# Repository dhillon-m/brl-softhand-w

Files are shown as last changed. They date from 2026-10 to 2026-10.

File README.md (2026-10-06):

# SoftHand Model-W

**A 3D-printed, anthropomorphic, underactuated robot hand with an integrated wrist and carpal tunnel**






Dhillon B. Merritt, Christopher J. Ford, Haoran Li, Malia Smith, Zhixing Chen, Efi Psomopoulou\*, Nathan F. Lepora\*  
*Bristol Robotics Laboratory, University of Bristol* · \*Equal contribution

This repository contains the CAD (STEP) and Python control code for the **SoftHand Model-W (SoftHand-W)**. The SoftHand-W is a 3D-printed hand based on the Pisa/IIT SoftHand. It adds an antagonistic tendon mechanism and a **2-DoF tendon-driven wrist**. Four servos drive it:

- **Fingers:** active flexion and extension of all five fingers.
- **Wrist:** active flexion/extension and radial/ulnar deviation of the palm.

The hand keeps the synergistic, self-adaptive grasping of the SoftHand family.

📄 **Paper:** [arXiv:2604.00738](https://arxiv.org/abs/2604.00738)

---

## Contents

- [Highlights](#highlights)
- [Hardware](#hardware)
- [CAD](#cad)
- [Software](#software)
- [Getting started](#getting-started)
- [Library reference](#library-reference)
- [Experiments](#experiments)
- [Citation](#citation)
- [Acknowledgements](#acknowledgements)
- [License](#license)

## Highlights

- **Underactuated and anthropomorphic.** Five fingers move together through adaptive synergies, driven by antagonistic flexor and extensor tendons.
- **2-DoF wrist** in a serial rotational-rotational layout:
  - **±90°** flexion/extension
  - **±30°** radial/ulnar deviation
- **Carpal-tunnel tendon routing.** The finger tendons pass through the wrist inside PTFE sheaths that work like Bowden cables. This means:
  - Moving the wrist doesn't make the fingers flex.
  - The motors can sit in the forearm, which keeps weight away from the hand.
- **Human-scale.** The hand is 164.6 mm from the base of the palm to the middle fingertip, which is within the 5th–95th percentile of adult hands.
- **Low-cost and easy to build.** It uses printed PLA, off-the-shelf servos and common hardware.

## Hardware

| Component | Details |
| --- | --- |
| Actuators | 4 × Feetech STS3215 serial bus servos (19.5 kg·cm at 7.4 V) |
| Servo interface | Feetech URT-1 controller, USB to PC |
| Structure | PLA (FDM); small precision parts in resin (SLA); CNC-milled aluminium parts |
| Tendons | Nylon thread, routed through PTFE tubing (carpal tunnel) |
| Fasteners | M2 screws and bearings. Tendons are anchored with an M2 bolt and washers, not knots. |
| Hand size | 164.6 mm tall; each finger 81.6 mm long |
| Wrist size | 54.5 mm (H) × 69.3 mm (W) × 41 mm (D) |
| Robot arm | Tested on a Universal Robots UR5 |

### Servo IDs

The code assumes the following servo IDs:

| ID | Function |
| -- | --- |
| 1  | Wrist flexion / extension |
| 2  | Finger extensor |
| 3  | Finger flexor |
| 4  | Wrist radial / ulnar deviation |

### Wrist kinematics

Distal Denavit–Hartenberg parameters of the wrist:

| Joint | Motion | a (mm) | α | d | θ  |
| ----- | --- | --- | --- | - | -- |
| 1 | Ulnar / radial deviation | 34 | π/2 | 0 | θ₁ |
| 2 | Flexion / extension | 48 | 0 | 0 | θ₂ |

## CAD

All parts are STEP files in [`cad/`](cad), grouped the same way as the original design. [`Assembly - Final.step`](cad) is the complete hand and wrist.

| Folder | Contents |
| --- | --- |
| [`cad/Fingers/`](cad/Fingers) | Proximal, intermediate and distal phalanges, the middle gear, phalange connectors, and a full finger assembly (plus an exploded view) |
| [`cad/Palm/`](cad/Palm) | Palm, palm covers, and the finger and palm layout |
| [`cad/Wrist/`](cad/Wrist) | The 2-DoF wrist (assembled and exploded) and the 16 mm bearing |
| [`cad/Actuation/`](cad/Actuation) | Tendon spools (finger, flexion, deviation), servo adapter, Bowden guides, and reference models of the STS3215 servo and 7 mm bearing |
| [`cad/Testing/`](cad/Testing) | Experiment parts: a UR5 tool flange adapter, a retaining bracket, the test cube and reorientation die, and a screw test piece |

The servo and bearing models are there for fitting checks only. Those parts are bought, not printed.

## Software

| File | Purpose |
| --- | --- |
| [`softhand_w_lib.py`](softhand_w_lib.py) | Servo control library: raw Feetech packet commands, hand open/close, wrist angle control and tool centre point (TCP) calculation |
| [`test_script.py`](test_script.py) | Cube-stacking experiment on a UR5. It logs joint angles and pose to CSV and plots the results. |

Wrist control is **open loop and proportional**. A requested angle is turned into a servo position by multiplying it by a constant gain and offsetting it from a calibrated centre value. Because the wrist moves the hand, the tool centre point also moves. `test_script.py` can run a background thread that recomputes the robot's TCP from the current wrist angles.

## Getting started

### Requirements

- Python 3.10+
- [`pyserial`](https://pypi.org/project/pyserial/), `numpy`, `matplotlib`
- For the UR5 experiments only: the Common Robot Interface (`cri`) package, which provides `SyncRobot`, `AsyncRobot` and `RTDEController`.

```sh
pip install pyserial numpy matplotlib
```

### Calibrate your hand

> ⚠️ **The servo positions in `softhand_w_lib.py` belong to one particular build.** Tendon length and how the horns are mounted differ between builds. Using these positions without checking them can over-tension the tendons.

1. Use the Feetech debugging software to find the open and closed positions of the flexor servo (ID 3) and the extensor servo (ID 2).
2. Update the values in `open_hand()` and `close_hand()`.
3. Check the wrist centre values in `move_wrist()` and `get_wrist_angles()`: `2048` for flexion and `2150` for deviation. Also check the travel limits.

### Minimal example

```python
import serial
import softhand_w_lib as swl

ser = serial.Serial("COM5", baudrate=1_000_000, timeout=0.1)  # change to your port

swl.home_hand(ser)                                   # open hand, centre wrist
swl.close_hand(ser)
swl.wait_for_servo(ser, servo_ids=[2, 3])

swl.move_wrist(ser, flexion_angle=45, ulnar_angle=0) # degrees
swl.wait_for_servo(ser, servo_ids=[1, 4])
print(swl.get_wrist_angles(ser))                     # (flexion°, ulnar°)

swl.open_hand(ser)
ser.close()
```

## Library reference

| Function | Description |
| --- | --- |
| `move_servo(ser, servo_id, position)` | Sends a raw position command (0–4095). |
| `read_servo_position(ser, servo_id)` | Reads the servo's current position, or returns `None` on error. |
| `read_servo_moving(ser, servo_id)` | Returns `True` if the servo is moving. |
| `wait_for_servo(ser, servo_ids, check_interval, timeout)` | Waits until every listed servo has stopped. |
| `open_hand(ser)` / `close_hand(ser)` | Drives the antagonistic flexor/extensor pair, in the right order. |
| `move_wrist(ser, flexion_angle, ulnar_angle)` | Moves the wrist to the given angles in degrees. Positions are clamped to safe limits. |
| `get_wrist_angles(ser)` | Reads the current wrist angles in degrees. |
| `compute_tcp_from_wrist(flexion_angle, ulnar_angle)` | Returns the TCP pose `[x, y, z, ax, ay, az]` for a 285 mm hand offset. |
| `home_hand(ser)` | Opens the hand, centres the wrist and waits for all servos to stop. |

Every serial access goes through one shared re-entrant lock, `swl.serial_lock`, so the library can be called from several threads, for example a logger and a TCP updater. Scripts should use this lock rather than creating their own.

## Experiments

The SoftHand-W was mounted on a UR5 and tested on two reorientation tasks. Each task was run with the wrist actuated and with it held fixed.

| Task | Without wrist | With wrist |
| --- | --- | --- |
| **Disc rotation** (90 mm disc, rotated 90°): time  | 66 s | **47 s** (~29% faster) |
| **Disc rotation**: configuration changes | 2 | **1** |
| **Cube stacking** (six 50 mm cubes): cubes stacked | 5 / 6 | **6 / 6** |
| **Cube stacking**: max travel of UR5 joint 4 | baseline | **~36% less** |

Using the wrist cut down how much the arm had to move to compensate, made the tasks faster, and made some pick-and-place moves possible that couldn't be done otherwise.

To rerun the cube-stacking task:

1. Set the serial port (`COM5`) and the UR5 IP address in `test_script.py`.
2. Check the cube and placement poses for your workspace.
3. Run `python test_script.py`. Logged data goes to `stack_no_wrist.csv`, and plots of joint angles and the end-effector path are shown at the end.

## Citation

If you use this work, please cite:

```bibtex
@article{merritt2026softhandw,
  title   = {SoftHand Model-W: A 3D-Printed, Anthropomorphic, Underactuated Robot Hand with Integrated Wrist and Carpal Tunnel},
  author  = {Merritt, Dhillon B. and Ford, Christopher J. and Li, Haoran and Smith, Malia and Chen, Zhixing and Psomopoulou, Efi and Lepora, Nathan F.},
  journal = {arXiv preprint arXiv:2604.00738},
  year    = {2026}
}
```

## Acknowledgements

This work was supported by the Advanced Research + Invention Agency (ARIA) under the grant *"Democratising Co-Design of Hardware and Control for Robot Dexterity"*.

The design builds on the Pisa/IIT SoftHand and the BRL SoftHand line, including the [MagProprio SoftHand](https://github.com/robotdexterity/MIT-x-BRL-Robot-Hand-with-Proprioception).

## License

Everything in this repository, including the code and the CAD files, is released under the [MIT License](LICENSE).

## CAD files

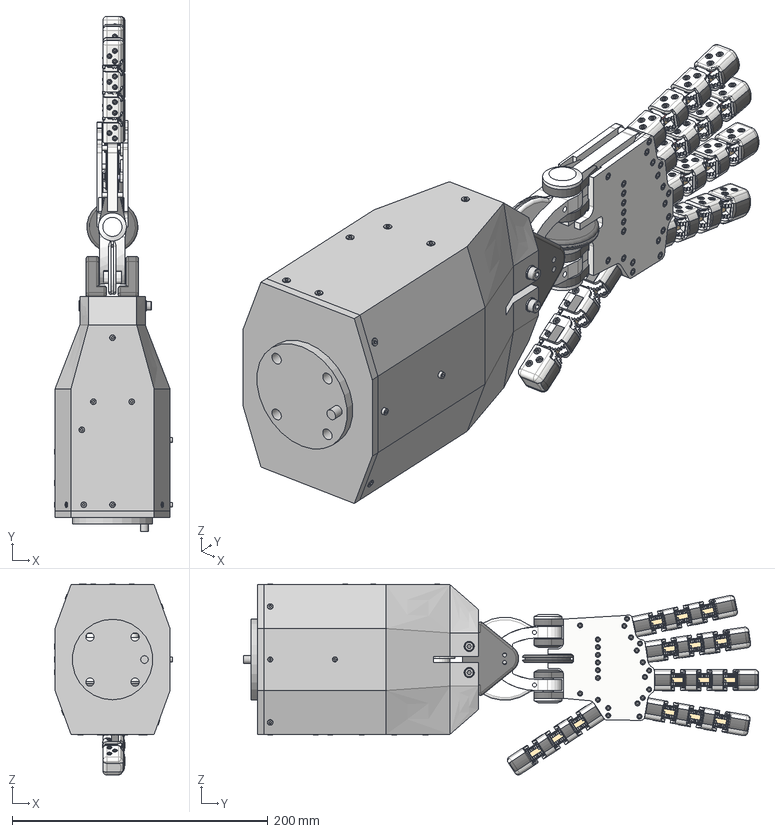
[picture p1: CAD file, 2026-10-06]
cad/Assembly - Final.step
92.5 x 402.9 x 149.4 mm
Servo - Feetech STS3215 x 4
Servo Adapter x 4
Front
Outer Ring x 4
Inner Ring x 4
Base Rear (1)
Base Front (1)
Deviation Axle (1)
Middle Link
Flex/Ext Axle
Flex/Ext Axle (1)
Cap x 2
M2_8mm x 25
phalange connector 11.95 mm x 15
Ring Magnet x 15
small bearing (ID is off) x 144
M2_10mm x 40
M2_5mm x 80
Middle Gear x 10
Pyramid Side Cover x 10
V Side Cover x 10
Cable- Pyr Side x 10
Cable- V Side x 10
3D FPC PLACEHOLDER NO LINK
3D FPC PLACEHOLDER NO LINK_1
middle gear_1 x 5
pyramid side cover_1 x 5
v side cover_1 x 5
CAPC1608X85 x 10
Middle Gear_2 x 5
Pyramid Side Cover_2 x 5
V Side Cover_2 x 5
Cable- Pyr Side_1 x 5
Cable- V Side_1 x 5
3D FPC PLACEHOLDER NO LINK_3
3D FPC PLACEHOLDER NO LINK_4
3D FPC PLACEHOLDER NO LINK_6
3D FPC PLACEHOLDER NO LINK_7
3D FPC PLACEHOLDER NO LINK_9
3D FPC PLACEHOLDER NO LINK_10
3D FPC PLACEHOLDER NO LINK_12
3D FPC PLACEHOLDER NO LINK_13
Flex/Ext Pulley
Palm_1
Back Cover
Inner Palm Cover
OT
IT
IP
OP
UR5 Tool Flange Adapter v2
Back
Bracket
Bracket finger
NF E25-514 - Z2.5 Steel 100 HV Plain x 24
DIN 912 - M2 x 0.4 x 5 Steel 4.6 Plain x 12
7mm OD 2mm ID Bearing x 4
DIN 912 - M2 x 0.4 x 10 Steel 4.6 Plain x 5
DIN 912 - M2.5 x 0.45 x 8 Steel 4.6 Plain x 30
NF E25-514 - Z4 Steel 100 HV Plain x 4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

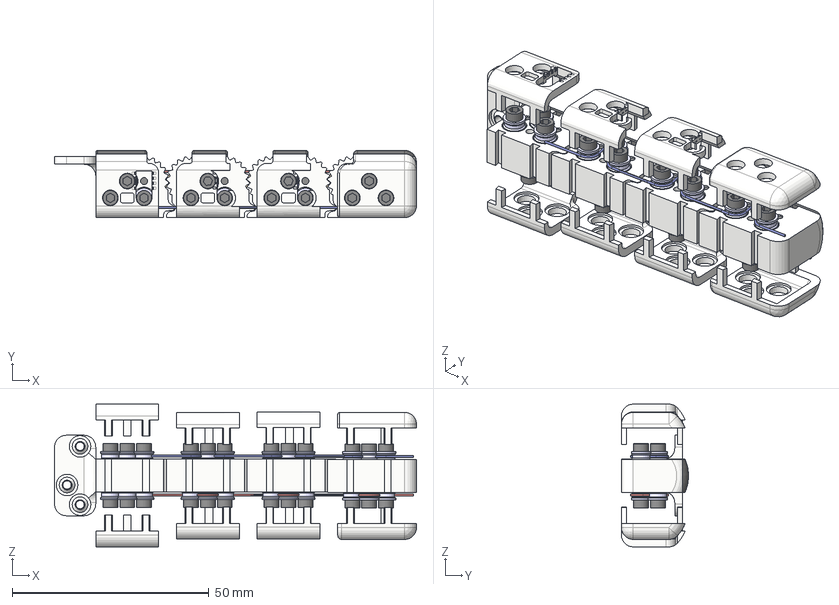
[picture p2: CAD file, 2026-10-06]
cad/Fingers/Assembled Finger - Exploded.step
92.1 x 17.1 x 36.3 mm
small bearing (ID is off) x 18
M2_10mm x 6
M2_5mm x 12
Middle Gear (2)
Pyramid Side Cover (2)
V Side Cover (2)
Cable- Pyr Side (2)
Cable- V Side (2)
Middle Gear (1)
Pyramid Side Cover (1)
V Side Cover (1)
Cable- Pyr Side (1)
Cable- V Side (1)
phalange connector 11.95 mm x 3
Ring Magnet x 3
small bearing (ID is off) v1
small bearing (ID is off) v1 (1)
small bearing (ID is off) v1 (2)
small bearing (ID is off) v1 (3)
small bearing (ID is off) v1 (4)
small bearing (ID is off) v1 (5)
M2_10mm v2
M2_10mm v2 (1)
M2_5mm v2
M2_5mm v2 (1)
M2_5mm v2 (2)
M2_5mm v2 (3)
middle gear
pyramid side cover
v side cover
Middle Gear_1
Pyramid Side Cover_1
V Side Cover_1
Cable- Pyr Side
Cable- V Side

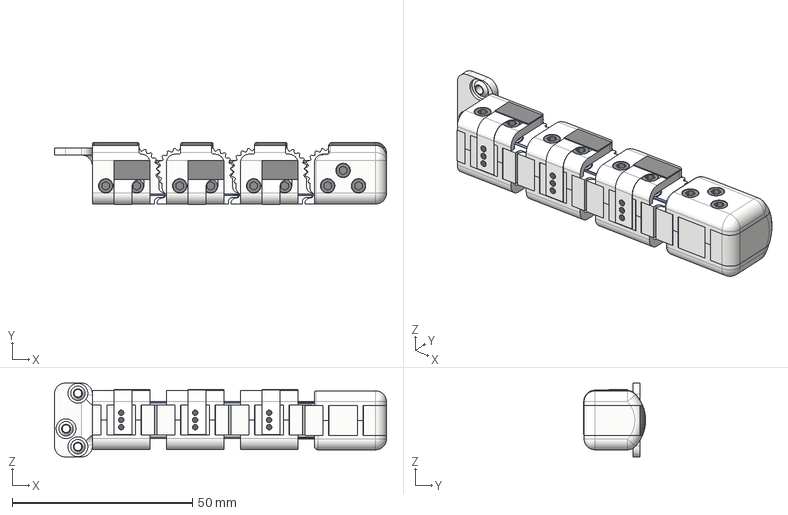
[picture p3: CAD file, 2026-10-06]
cad/Fingers/Assembled Finger.step
92.1 x 17.3 x 20.5 mm
phalange connector 11.95 mm x 3
Ring Magnet x 3
small bearing (ID is off) x 24
M2_10mm x 8
M2_5mm x 16
Middle Gear x 2
Pyramid Side Cover x 2
V Side Cover x 2
Cable- Pyr Side x 2
Cable- V Side x 2
3D FPC PLACEHOLDER NO LINK
3D FPC PLACEHOLDER NO LINK_1
middle gear_1
pyramid side cover_1
v side cover_1
CAPC1608X85 x 2
Middle Gear_2
Pyramid Side Cover_2
V Side Cover_2
Cable- Pyr Side_1
Cable- V Side_1

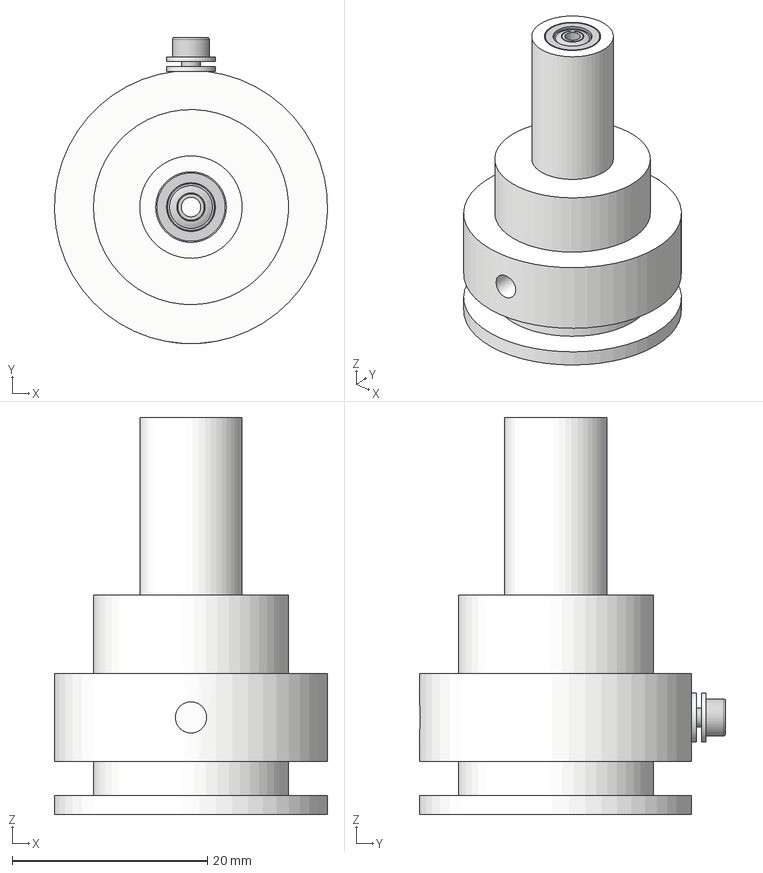
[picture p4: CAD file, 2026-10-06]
cad/Actuation/Spool - Deviation.step
28.0 x 31.4 x 40.7 mm
NF E25-514 - Z2.5 Steel 100 HV Plain x 2
DIN 912 - M2 x 0.4 x 5 Steel 4.6 Plain
7mm OD 2mm ID Bearing

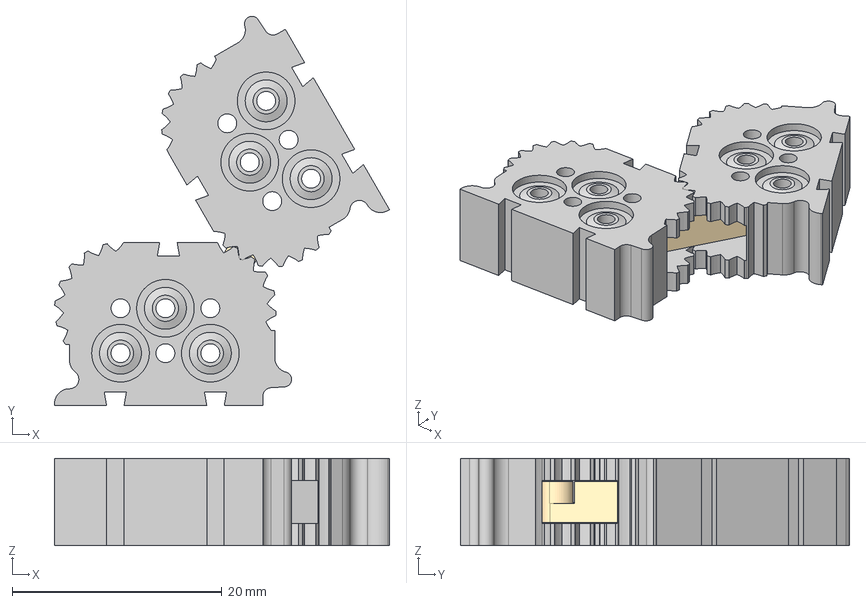
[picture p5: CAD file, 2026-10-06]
cad/Fingers/Visualising Gear Motion.step
32.0 x 37.1 x 8.33 mm
Middle Gear x 2
phalange connector 11.80 mm

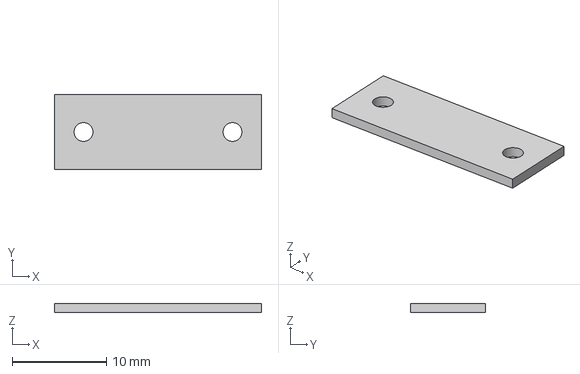
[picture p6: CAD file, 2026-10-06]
cad/Palm/Finger + Palm Layout.step
22.0 x 8.00 x 1.00 mm

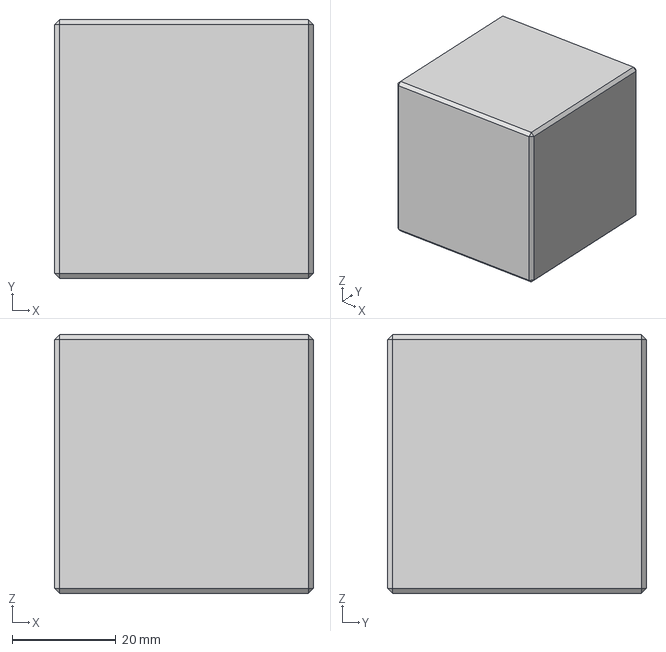
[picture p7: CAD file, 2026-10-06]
cad/Testing/Cube.step
50.0 x 50.0 x 50.0 mm

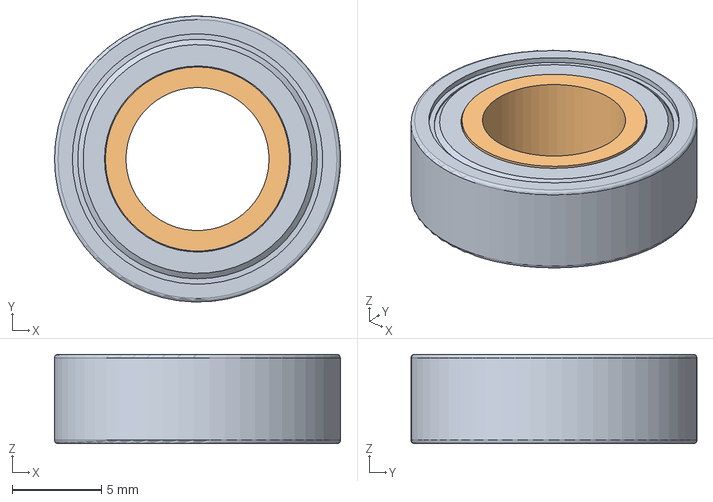
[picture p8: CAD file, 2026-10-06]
cad/Wrist/16mmOD 8mmID Bearing.step
16.0 x 16.0 x 5.00 mm
Outer Ring
Inner Ring

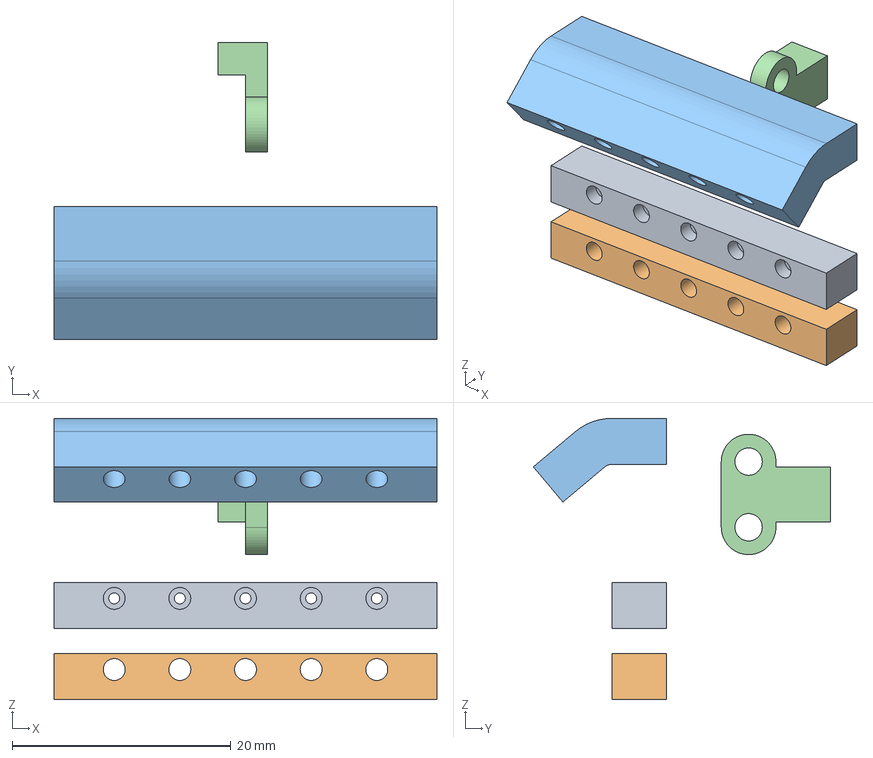
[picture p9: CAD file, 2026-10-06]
cad/Actuation/Bowden Guides.step
35.0 x 27.2 x 25.7 mm
Bowden Terminator
Bowden Bracket
Bowden Terminator (1)

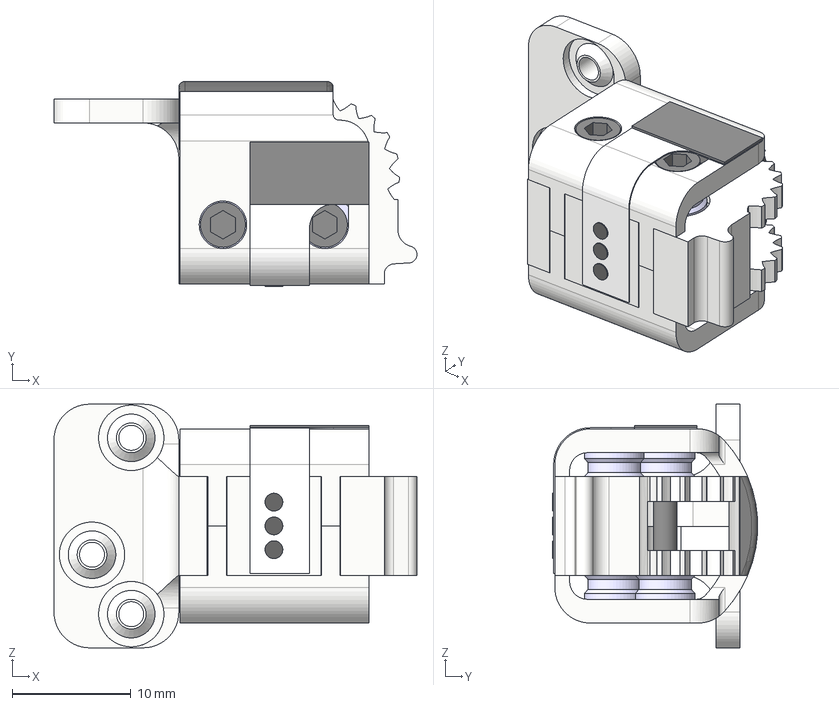
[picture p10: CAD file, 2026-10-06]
cad/Fingers/Phalanx - Proximal.step
30.5 x 17.3 x 20.5 mm
small bearing (ID is off) x 6
M2_10mm x 2
M2_5mm x 4
middle gear
pyramid side cover
v side cover
CAPC1608X85 x 2

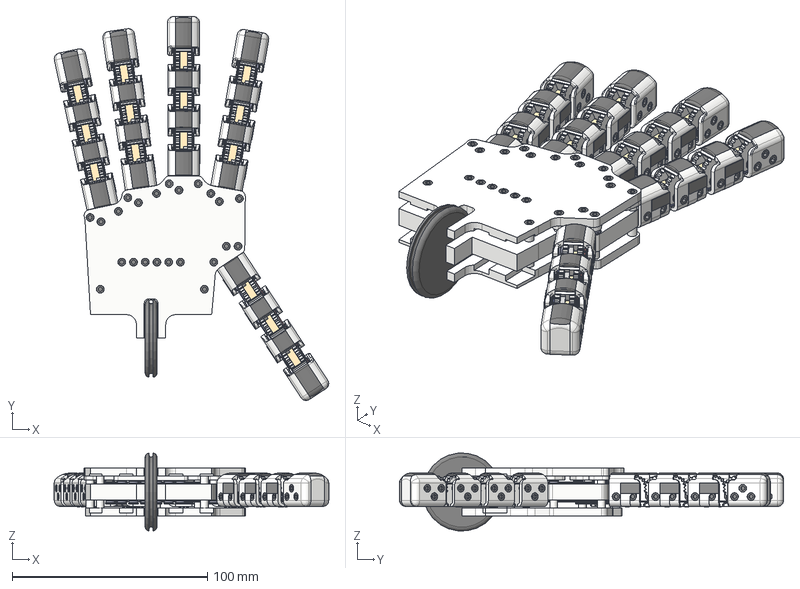
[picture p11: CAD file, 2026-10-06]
cad/Palm/Palm Covers.step
140.5 x 196.5 x 39.8 mm
M2_8mm x 25
phalange connector 11.95 mm x 15
Ring Magnet x 15
small bearing (ID is off) x 144
M2_10mm x 40
M2_5mm x 80
Middle Gear x 10
Pyramid Side Cover x 10
V Side Cover x 10
Cable- Pyr Side x 10
Cable- V Side x 10
3D FPC PLACEHOLDER NO LINK
3D FPC PLACEHOLDER NO LINK_1
middle gear_1 x 5
pyramid side cover_1 x 5
v side cover_1 x 5
CAPC1608X85 x 10
Middle Gear_2 x 5
Pyramid Side Cover_2 x 5
V Side Cover_2 x 5
Cable- Pyr Side_1 x 5
Cable- V Side_1 x 5
3D FPC PLACEHOLDER NO LINK_3
3D FPC PLACEHOLDER NO LINK_4
3D FPC PLACEHOLDER NO LINK_6
3D FPC PLACEHOLDER NO LINK_7
3D FPC PLACEHOLDER NO LINK_9
3D FPC PLACEHOLDER NO LINK_10
3D FPC PLACEHOLDER NO LINK_12
3D FPC PLACEHOLDER NO LINK_13
Flex/Ext Pulley
Palm_1
Back Cover
Inner Palm Cover

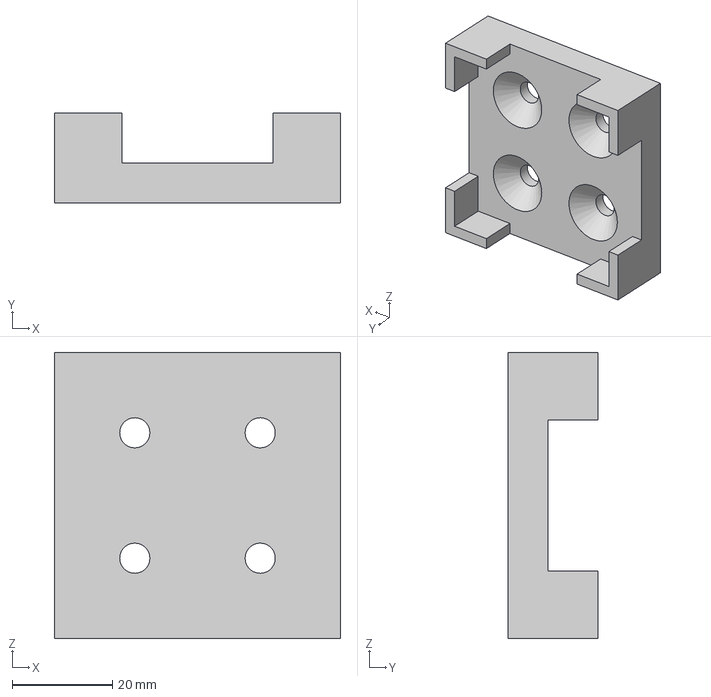
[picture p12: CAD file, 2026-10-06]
cad/Testing/Retaining Bracket.step
57.0 x 18.0 x 57.0 mm

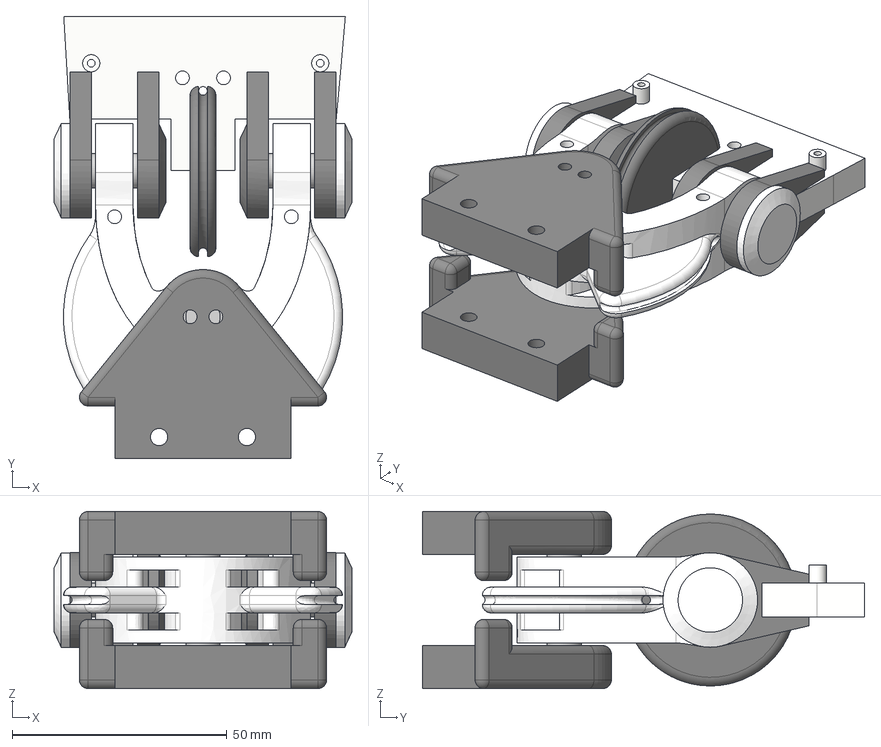
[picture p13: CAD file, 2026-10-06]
cad/Wrist/Wrist - Exploded.step
69.3 x 102.9 x 41.2 mm
Outer Ring x 4
Inner Ring x 4
Base Rear (1)
Deviation Axle (1)
Middle Link
Flex/Ext Axle
Flex/Ext Axle (1)
Cap x 2
Base Front (1)
Flex/Ext Pulley
Palm
OT
IT
IP
OP

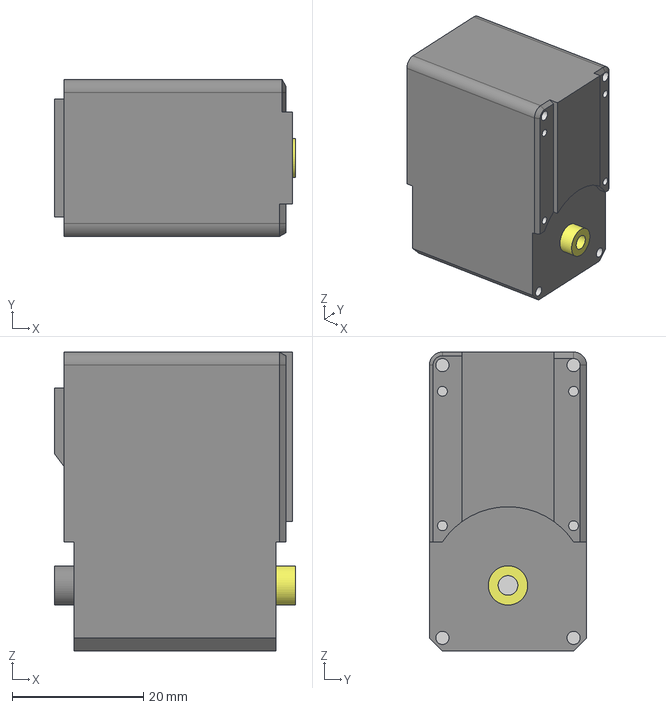
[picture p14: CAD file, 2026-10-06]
cad/Actuation/Servo - Feetech STS3215.step
36.8 x 24.0 x 45.6 mm

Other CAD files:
cad/Fingers/Phalanx - Distal.step
cad/Palm/Palm.step
cad/Testing/UR5 Tool Flange Adapter.step
cad/Wrist/Wrist.step
cad/Actuation/7mm OD 2mm ID Bearing.step
cad/Actuation/Servo Adapter.step
cad/Actuation/Spool - Finger.step
cad/Actuation/Spool - Flexion.step
cad/Actuation/Spools.step
cad/Fingers/Middle Gear.step
cad/Fingers/Phalange Connector Stronger.step
cad/Fingers/Phalange Connector.step
cad/Fingers/Phalanx - Intermediate.step
cad/Testing/Reorientation Die.step
cad/Testing/Screw Test.step

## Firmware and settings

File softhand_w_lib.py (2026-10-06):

import time
import threading
# Serial port lock for thread safety (re-entrant so callers can hold it across several reads)
serial_lock = threading.RLock()

##################################
# Useful for any servo operation #
##################################

def checksum(packet):
    """
    Calculate the checksum for a given packet.
    :param packet: List of integers representing the packet
    :return: Checksum value
    """
    return (~sum(packet[2:])) & 0xFF


def read_servo_position(ser, servo_id):
    """
    Read the current position of a servo.
    :param ser: Open serial port
    :param servo_id: ID of the servo to read
    :return: Position value (int) or None if error
    """
    with serial_lock:
        ser.reset_input_buffer()
        packet = [0xFF, 0xFF, servo_id, 0x04, 0x02, 0x38, 0x01]  # 0x38 is the address for present position
        packet.append((~sum(packet[2:])) & 0xFF)
        ser.write(bytearray(packet))
        response = ser.read(8)
        if len(response) == 8 and response[0] == 0xFF and response[1] == 0xFF:
            pos_l = response[5]
            pos_h = response[6]
            position = pos_l + (pos_h << 8)
            return position
        return None


def read_servo_moving(ser, servo_id):
    """
    Check if a specific servo is currently moving.
    :param ser: Open serial port
    :param servo_id: ID of the servo to check
    :return: True if the servo is moving, False if not, None if an error occurs
    """
    with serial_lock:
        ser.reset_input_buffer()
        packet = [0xFF, 0xFF, servo_id, 0x04, 0x02, 0x42, 0x01]
        packet.append((~sum(packet[2:])) & 0xFF)
        ser.write(bytearray(packet))
        response = ser.read(7)
        if len(response) == 7 and response[0] == 0xFF and response[1] == 0xFF:
            moving = response[5]
            return moving == 1
        return None


def wait_for_servo(ser, servo_ids=[1, 2, 3, 4], check_interval=0.1, timeout=10):
    """
    Wait until all specified servos have stopped moving.
    :param ser: Open serial port
    :param servo_ids: List of servo IDs to check
    :param check_interval: Time in seconds between checks
    :param timeout: Maximum time to wait in seconds
    :return: True if all servos are stopped, False if timeout
    """
    start_time = time.time()
    
    while time.time() - start_time < timeout:
        all_stopped = True
        for servo_id in servo_ids:
            moving = read_servo_moving(ser, servo_id)
            if moving is None:
                return False
            if moving:
                all_stopped = False
        if all_stopped:
            return True
        time.sleep(check_interval)
        
    print("Timeout reached before all servos stopped.")
    return False


def move_servo(ser, servo_id, position):
    """
    Move a specific servo to the given position.
    :param ser: Open serial port
    :param servo_id: ID of the servo to move
    :param position: Position value to move the servo to (0-4095)
    """
    with serial_lock:
        pos_l = position & 0xFF         # Low byte of position
        pos_h = (position >> 8) & 0xFF  # High byte of position
        
        packet = [0xFF, 0xFF, servo_id, 0x05, 0x03, 0x2A, pos_l, pos_h]
        packet.append(checksum(packet))
        
        ser.write(bytearray(packet))



#################################
# Useful for SoftHand-W control #
#################################

# !!WARNING!!: The positions below must be adjusted for your specific hand
# Use the Feetech software to find the correct positions for your servos

def close_hand(ser):
    """
    Close the hand.
    :param ser: Open serial port
    """
    move_servo(ser, servo_id=2, position=3200) # Position of extensor servo when hand is closed
    time.sleep(0.2)
    move_servo(ser, servo_id=3, position=3200) # Position of flexor servo when hand is closed
    time.sleep(0.05)


def open_hand(ser):
    """
    Open the hand.
    :param ser: Open serial port
    """
    move_servo(ser, servo_id=3, position=750) # Position of flexor servo when hand is open
    time.sleep(0.2)
    move_servo(ser, servo_id=2, position=450) # Position of extensor servo when hand is open
    time.sleep(0.05)



###############################
# Specific for the SoftHand-W #
###############################

def move_wrist(ser, flexion_angle, ulnar_angle):
    """
    Move the wrist to the specified positions.
    :param ser: Open serial port
    :param flexion_angle: Wrist flexion/extension angle in degrees (servo 1)
    :param ulnar_angle: Ulnar/radial deviation angle in degrees (servo 4)
    """
    # Joint mapping
    flexion_deg_per_pos = 360 / (1.8 * (4095 - 0))
    flexion_min_angle = (0 - 2048) * flexion_deg_per_pos
    flexion_max_angle = (4095 - 2048) * flexion_deg_per_pos
    
    ulnar_deg_per_pos = 360 / (1.5 * (3100 - 1200))
    ulnar_min_angle = (1200 - 2150) * ulnar_deg_per_pos
    ulnar_max_angle = (3100 - 2150) * ulnar_deg_per_pos
    
    # Convert wrist angles to servo positions
    flexion_pos = int(round(2048 + (flexion_angle / flexion_deg_per_pos)))
    flexion_pos = max(1500, min(4095, flexion_pos))

    ulnar_pos = int(round(2150 + (ulnar_angle / ulnar_deg_per_pos)))
    ulnar_pos = max(1200, min(3100, ulnar_pos))
    
    # Move servos to the calculated positions
    move_servo(ser, servo_id=1, position=flexion_pos)
    time.sleep(0.05)
    move_servo(ser, servo_id=4, position=ulnar_pos)
    time.sleep(0.05)


def get_wrist_angles(ser):
    """
    Read servo positions and convert to wrist angles (flexion, ulnar).
    :param ser: Open serial port
    :return: (flexion_angle_deg, ulnar_angle_deg) or (None, None) if error
    """
    flexion_pos = read_servo_position(ser, servo_id=1)
    ulnar_pos = read_servo_position(ser, servo_id=4)
    if flexion_pos is None or ulnar_pos is None:
        return (None, None)
    # Use same mapping as move_wrist
    flexion_deg_per_pos = 360 / (1.8 * (4095 - 0))
    flexion_angle = (flexion_pos - 2048) * flexion_deg_per_pos
    ulnar_deg_per_pos = 360 / (3.05 * (3100 - 1200))
    ulnar_angle = (ulnar_pos - 2150) * ulnar_deg_per_pos
    return (flexion_angle, ulnar_angle)
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

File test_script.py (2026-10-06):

##############################
# Import necessary libraries #
##############################

import serial
import serial.tools.list_ports
import time
import numpy as np
import csv
import threading
import matplotlib.pyplot as plt
import matplotlib.animation as animation
from mpl_toolkits.mplot3d import Axes3D

import softhand_w_lib as swl
from cri.robot import SyncRobot, AsyncRobot
from cri.controller import RTDEController

# Share the library's serial port lock so all threads are serialised on one lock
serial_lock = swl.serial_lock


################
# Data storage #
################

# Logging buffers
timestamps, joint_data, pose_data = [], [], []

# Sampler thread control
_log_stop = threading.Event()
_log_thread = None
start_time = None

def _sampler(robot, dt = 0.01):
    """Poll robot state at fixed rate and append to buffers."""
    while not _log_stop.is_set():
        t = time.time() - start_time
        try:
            j = tuple(robot.joint_angles)
            p = tuple(robot.pose)
            timestamps.append(t)
            joint_data.append(j)
            pose_data.append(p)
        except Exception:
            pass
        time.sleep(dt)

def start_logger(robot, dt = 0.01):
    """Begin background logging of robot state."""
    global _log_thread, start_time
    start_time = time.time()
    _log_stop.clear()
    _log_thread = threading.Thread(target=_sampler, args=(robot, dt), daemon=True)
    _log_thread.start()
    
def stop_logger():
    """Stop background logging of robot state."""
    _log_stop.set()
    if _log_thread is not None:
        _log_thread.join()

def save_to_csv(filename):
    """Save logged data to a CSV file."""
    header = ["time_s"] + [f"joint_{i+1}_deg" for i in range(6)] + \
             ["x_mm", "y_mm", "z_mm", "rx_deg", "ry_deg", "rz_deg"]
    with open(filename, "w", newline="") as f:
        w = csv.writer(f)
        w.writerow(header)
        for t, j, p in zip(timestamps, joint_data, pose_data):
            w.writerow([t] + list(j) + list(p))


##############################
# Real-time TCP update thread #
##############################

_tcp_stop = threading.Event()
_tcp_thread = None

def _tcp_updater(robot, ser, dt=0.01):
    """Update robot TCP in real time based on wrist angles."""
    while not _tcp_stop.is_set():
        with serial_lock:
            flexion_angle, ulnar_angle = swl.get_wrist_angles(ser)
        if flexion_angle is not None and ulnar_angle is not None:
            tcp_pose = swl.compute_tcp_from_wrist(flexion_angle, ulnar_angle)
            robot.tcp = tuple(tcp_pose)
        time.sleep(dt)

def start_tcp_updater(robot, ser, dt=0.01):
    global _tcp_thread
    _tcp_stop.clear()
    _tcp_thread = threading.Thread(target=_tcp_updater, args=(robot, ser, dt), daemon=True)
    _tcp_thread.start()

def stop_tcp_updater():
    _tcp_stop.set()
    if _tcp_thread is not None:
        _tcp_thread.join()


################################
# Setup wrist and hand control #
################################

# List available serial ports
ports = serial.tools.list_ports.comports()
for port in ports:
    print(port.device)

# Open serial port
ser = serial.Serial('COM5', baudrate=1000000, timeout=0.1)


###############
# Test Script #
###############

# Set up base and work coordinate frames
base_frame = (0, 0, 0, 0, 0, 0)
work_frame = (10, -580, 350, 90, 0, 0)   # base frame: x->right, y->back, z->up

# Configure UR5 robot
with AsyncRobot(SyncRobot(RTDEController(ip='192.168.1.164'))) as robot:
    robot.axes = 'sxyz'
    robot.tcp = (0, 0, 285, 0, 0, 0)
    robot.linear_speed = 100
    robot.angular_speed = 100
    robot.coord_frame = work_frame
    
    # Home position
    robot.move_linear((0, 0, 0, 0, 0, 0))
    swl.home_hand(ser)
    
    # Start logging robot state
    start_logger(robot, dt=0.01)

    ##############
    # Operations #
    ##############

    # Cube 1
    robot.move_linear((196, -162, 2, 0, 5, 0))   # Above cube
    robot.move_linear((196, -262, 2, 0, 5, 0))   # Lower to cube
    swl.close_hand(ser)
    swl.wait_for_servo(ser, servo_ids=[2,3])
    time.sleep(10)
    robot.move_linear((196, -162, 2, 0, 5, 0))

    # Place 1
    # swl.move_wrist(ser, 0, 60)
    robot.move_linear((-100, -171, 185, 0, 45, 0))
    robot.move_linear((-100, -271, 185, 0, 45, 0))
    swl.open_hand(ser)
    swl.wait_for_servo(ser, servo_ids=[2,3])
    time.sleep(2)
    robot.move_linear((-100, -171, 185, 0, 45, 0))
    # swl.move_wrist(ser, 0, 0)



    # Cube 2
    robot.move_linear((321, -162, 2, 0, 5, 0))   # Above cube
    robot.move_linear((321, -262, 2, 0, 5, 0))   # Lower to cube
    swl.close_hand(ser)
    swl.wait_for_servo(ser, servo_ids=[2,3])
    time.sleep(10)
    robot.move_linear((321, -162, 2, 0, 5, 0))

    # Place 2
    # swl.move_wrist(ser, 0, -60)
    robot.move_linear((32, -171, 127, 0, -64, 0))
    robot.move_linear((32, -271, 127, 0, -64, 0))
    swl.open_hand(ser)
    swl.wait_for_servo(ser, servo_ids=[2,3])
    time.sleep(2)
    robot.move_linear((32, -171, 127, 0, -64, 0))
    # swl.move_wrist(ser, 0, 0)



    # Cube 3
    robot.move_linear((196, -171, 127, 0, 5, 0))   # Above cube
    robot.move_linear((196, -271, 127, 0, 5, 0))   # Lower to cube
    swl.close_hand(ser)
    swl.wait_for_servo(ser, servo_ids=[2,3])
    time.sleep(10)
    robot.move_linear((196, -171, 127, 0, 5, 0))

    # Place 3
    robot.move_linear((-102, -182, 160, 0, 0, 90))
    robot.move_linear((-102, -282, 160, 0, 0, 90))
    swl.open_hand(ser)
    swl.wait_for_servo(ser, servo_ids=[2,3])
    time.sleep(2)
    robot.move_linear((-102, -182, 160, 0, 0, 90))


    # Cube 4
    robot.move_linear((321, -171, 127, 0, 5, 0))   # Above cube
    robot.move_linear((321, -271, 127, 0, 5, 0))   # Lower to cube
    swl.close_hand(ser)
    swl.wait_for_servo(ser, servo_ids=[2,3])
    time.sleep(10)
    robot.move_linear((321, -171, 127, 0, 5, 0))

    # Place 4
    robot.move_linear((59, -141, 152, 0, 0, -90))
    robot.move_linear((59, -241, 152, 0, 0, -90))
    swl.open_hand(ser)
    swl.wait_for_servo(ser, servo_ids=[2,3])
    time.sleep(2)
    robot.move_linear((59, -141, 152, 0, 0, -90))



    # Cube 5
    robot.move_linear((196, -171, 252, 0, 5, 0))   # Above cube
    robot.move_linear((196, -271, 252, 0, 5, 0))   # Lower to cube
    swl.close_hand(ser)
    swl.wait_for_servo(ser, servo_ids=[2,3])
    time.sleep(10)
    robot.move_linear((196, -171, 252, 0, 5, 0))

    # Place 5
    # swl.move_servo(ser, 1, 450)
    robot.move_linear((-100, 105, 155, -80, 0, 0))
    robot.move_linear((-100, 95, 155, -80, 0, 0))
    swl.open_hand(ser)
    swl.wait_for_servo(ser, servo_ids=[2,3])
    time.sleep(2)
    robot.move_linear((-100, 105, 155, -80, 0, 0))
    # swl.move_servo(ser, 1, 2047)
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

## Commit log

2026-10-06 Rewrite README, add MIT license and tidy repo
    - README based on the SoftHand Model-W paper (arXiv:2604.00738):
    hardware, servo IDs, wrist kinematics, usage, experiments, citation
    - Share one re-entrant serial lock between the library and test_script
    - Fix move_wrist docstring (deviation is servo 4, args are degrees)
    - Stop tracking __pycache__ and .vscode; add .gitignore
    [softhand_w_lib.py, test_script.py]
2026-10-06 Add SoftHand-W CAD (STEP files)
    [16mmOD 8mmID Bearing.step, 7mm OD 2mm ID Bearing.step, Assembled Finger - Exploded.step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]
2026-10-06 Clarify MIT license covers CAD

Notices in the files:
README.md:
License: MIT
